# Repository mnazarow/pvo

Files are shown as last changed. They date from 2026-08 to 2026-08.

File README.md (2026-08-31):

# ПВО от комаров 🦟🎯 — карта проекта

Поворотная турель с лазером-целеуказателем по мотивам вирусного видео. Четыре варианта исполнения, у каждого — свой код и своё руководство по сборке.

## Какой файл к какому варианту

| Вариант | Железо | Код | Руководство по сборке |
|---|---|---|---|
| **A «Часовой»** | Uno/Nano + HC-SR04 + 1 серво | `pvo_a_simple/pvo_a_simple.ino` (минимальный) или `pvo.ino` (полный) | `Сборка_вариант_A.docx` |
| **B «Комар-М»** — как в видео | ESP32 + радар LD2450/RD-03D + pan-tilt | `pvo_esp32/pvo_esp32.ino` | `Сборка_вариант_B.docx` |
| **C «Комар-В»** — зрение | Raspberry Pi + камера + турель A | `pvo_vision.py` (на Pi) + `pvo.ino` (в турели) | `Сборка_вариант_C.docx` |
| **D «Комар-Ф»** — слияние | турель B + камера на ней (без ИК-фильтра) + ИК-подсветка | `pvo_fusion.py` (на Pi, рядом кладётся `pvo_vision.py`) + `pvo_esp32.ino` | `Сборка_вариант_D.docx` |

## Общие файлы

- **`ПВО_от_комаров_руководство.docx`** — главный документ: методология, выбор компонентов, программирование, подробное описание **каждого** параметра с примерами, GUI-пульт, эксплуатация, диагностика, замены компонентов.
- **`pvo_gui.py`** — «Пульт ПВО»: приложение для Windows/macOS (Python + pyserial). Живой радарный экран, настройка всех параметров без перепрошивки, ручное управление, консоль. Запуск: `pip install pyserial`, затем `python pvo_gui.py`.
- **`ПВО_список_покупок.xlsx`** — чеклист закупки с ценами и итогами по конфигурациям.
- **`ПВО_с_нуля_для_новичка.docx`** — 59 страниц для человека, который никогда не занимался электроникой: что купить и как не ошибиться, словарь терминов, установка программ со скриншотами, сборка по одному проводу с проверками, каждая настройка простыми словами, типичные ошибки, частые вопросы. Ведёт через все четыре варианта по порядку.
- **`ПВО_шпаргалка_А4.pdf`** — одна страница со всеми командами, параметрами, распиновками и «первой помощью». Распечатать и держать у верстака.
- **`systemd/`** — готовые файлы служб для Raspberry Pi: `pvo.service` (вариант C) и `pvo-fusion.service` (вариант D).

## Быстрый старт (вариант A за вечер)

1. Купите по разделам 1–3 чеклиста (~2200 ₽).
2. Соберите по `Сборка_вариант_A.docx` (схема + 5 шагов).
3. Прошейте `pvo.ino` (Arduino IDE, плата Uno/Nano, порт 9600).
4. Самотест пройдёт сам; поднесите руку — захват, лазер, «поражение» в журнал.
5. Тонкая настройка — из `pvo_gui.py` (вкладка «Параметры», кнопка W сохраняет в плату).

## Демо и тесты — железо не нужно

- В пульте (`pvo_gui.py`) выберите порт **«ДЕМО: Uno»** или **«ДЕМО: ESP32»** — подключитесь к встроенной виртуальной турели: живой радар, параметры, журнал. Идеально, пока посылка едет.
- **Эмулятор AVR**: `bash tests/avr/run_scenarios.sh` — настоящая прошивка, собранная `avr-gcc`, исполняется по тактам (avr8js, движок Wokwi): видно размер во flash/RAM, реальные тайминги и EEPROM, переживающую перезагрузку. Установка: `sudo apt install gcc-avr avr-libc arduino-core-avr` и `(cd tests/avr/js && npm install)`.
- `bash tests/run_tests.sh` — автотесты всего проекта (для GitHub готов workflow: `tests/github-workflow-tests.yml` → скопировать в `.github/workflows/`): обе прошивки компилируются и гоняются по сценариям на заглушках Arduino API (g++), плюс тесты зрения и GUI. Подробности — `tests/README.md`.
- Каждое «поражение» пульт пишет в журнал с временем и координатами; кнопка «Сохранить CSV…» выгружает статистику для Excel. Вариант C с ключом `--save-hits` дополнительно сохраняет кадры захватов в `hits/`.

## Опциональные модули (включаются одним `#define`, глава 12 руководства)

- **Веб-панель по Wi-Fi** (вариант B, включена по умолчанию): турель раздаёт сеть `PVO-Komar`, радар и все параметры — в браузере телефона на `http://192.168.4.1`. Смените пароль в скетче!
- **OLED SSD1306** (`USE_OLED 1`): экран статуса прямо на турели (SDA=21, SCL=22).
- **Озвучка DFPlayer Mini** (`USE_DFPLAYER 1`): «Цель захвачена» вашим голосом; дорожки `/mp3/0001..0005.mp3`, библиотека не нужна.
- **Telegram** (варианты C и D): `PVO_TG_TOKEN`/`PVO_TG_CHAT` — уведомления о захватах с фотокадром.
- **Слияние радара и зрения** (вариант D, глава 13): радар будит зрение и грубо доворачивает турель, камера на турели ведёт цель с точностью 0,1°; ИК-подсветка (GPIO18) открывает охоту на мелочь, которую радар не видит. Запуск: `python3 pvo_fusion.py --detector bright`.
- **Пристрелка лазера** (вариант D): `python3 pvo_fusion.py --calibrate` — скрипт зажигает лазер, находит его точку в кадре и целится потом именно в неё, а не в центр кадра. Без этого шага система стабильно мажет на величину смещения камеры от лазера.
- **Предохранитель сопровождения** (обе прошивки): `TRACKMAX` (по умолчанию 60 с) не даёт турели вести одну «цель» бесконечно — штору на сквозняке или вентилятор. По лимиту лазер и ИК гаснут, турель берёт паузу `TRACKCD`.
- **3D-печать** (`3d/`): параметрический pan-tilt кронштейн, основание варианта A и держатель камеры с кольцом ИК-диодов (вариант D) — .scad + готовые STL + превью.

## Протокол (для своих скриптов)

Текстовые строки + `\n`. Uno 9600: `P<угол>` `R` `?` `G` `S ИМЯ ЗНАЧ` `W` `D` `Z` `M1/M0`. ESP32 115200: `?` `C` `L1/L0` `T` `G` `S …` `W` `D` `Z` `M1/M0` + `V dP dT` (поправка зрения, десятые градуса) и `I1/I0` (ИК) для варианта D. Подробно — руководство, разделы 3.9, 4.5 и глава 13. Версия прошивок печатается при старте и в статусе.

## Безопасность

Лазер — только ≤5 мВт (KY-008). Автонаводящийся лазер мощнее — это травма зрения, а не игрушка. Не ставьте турель на уровне глаз. ИК-подсветка в варианте D — только рассеянные светодиоды, никаких ИК-лазеров: инфракрасный луч невидим, и моргательный рефлекс глаз не защищает.

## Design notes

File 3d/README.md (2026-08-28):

# 3D-печать для «ПВО от комаров»

Параметрические модели OpenSCAD + готовые STL. Перед печатью **замерьте свои серво штангенциркулем** — у клонов SG90/MG90S размеры гуляют на ±0,5 мм; параметры правятся в начале каждого .scad (бесплатный редактор: openscad.org).

## Файлы

| Файл | Что это | STL |
|---|---|---|
| `pvo_pan_tilt.scad` | кронштейн pan-tilt для варианта B: плита с окном PAN-серво, Г-скоба на качалку с окном TILT-серво, площадка радара и лазера с прорезями под стяжки | `stl/pan_tilt_base.stl`, `stl/pan_tilt_bracket.stl`, `stl/pan_tilt_plate.stl` |
| `pvo_base_a.scad` | основание варианта A: окно серво + поле отверстий (шаг 10 мм) под Arduino/макетку на стяжках | `stl/base_a.stl` |
| `pvo_cam_mount.scad` | держатель камеры с кольцом ИК-диодов для варианта D: лицевая панель (окно объектива, 6 гнёзд под диоды 5 мм, винты М2) + люлька с вертикальными пазами регулировки высоты | `stl/cam_face.stl`, `stl/cam_cradle.stl` |

Превью: `preview_pan_tilt.png`, `preview_base_a.png`, `preview_cam_mount.png`.

## Печать

PLA или PETG · слой 0,2 мм · 3 периметра · заполнение 25% · все детали печатаются плашмя, поддержки не нужны. Отверстия под саморезы 2 мм и стяжки уже в моделях; если саморез идёт туго — пройдите отверстие сверлом 2 мм.

## Сборка pan-tilt

1. Плиту (base) — на основание, серво PAN в окно ушами вниз, прикрутить саморезами из комплекта серво.
2. Скобу (bracket) подошвой на круглую крестовину качалки PAN (4 самореза M2 по кругу).
3. Серво TILT — в окно стенки скобы, качалкой наружу.
4. Площадку (plate) — отверстиями на крестовину качалки TILT.
5. Радар и лазер — стяжками в прорези площадки (радар излучателем вперёд, лазер параллельно).
6. Только после прошивки и команды «C» (серво в центры) окончательно затянуть винты качалок «прямо и в горизонт».

## Сборка держателя камеры (вариант D)

В варианте D камера — это прицел: её ось должна быть параллельна лучу лазера и не сдвигаться после пристрелки. Термоклей столько не держит, поэтому камера садится на печатный держатель.

1. Камеру — на лицевую панель (`cam_face`) четырьмя винтами М2, объектив в центральное окно. Плата камеры сзади, объектив смотрит наружу.
2. ИК-диоды 5 мм — в кольцо гнёзд вокруг объектива, ножками назад; спаять параллельно (все аноды вместе, все катоды вместе) и вывести два провода на ключ GPIO18. Если берёте готовую ИК-плату — поставьте `ir_module = true` в начале .scad, и вместо кольца получится окно под неё.
3. Люльку (`cam_cradle`) — стяжками в прорези площадки TILT рядом с лазером, объективом в ту же сторону.
4. Панель — к стойке люльки двумя винтами М2 через **вертикальные пазы**: до затяжки подвиньте панель так, чтобы ось объектива встала на высоту оси лазера. Это и есть механическая часть пристрелки.
5. Остаточное смещение снимается программно: `python3 pvo_fusion.py --calibrate` (глава 13 руководства).

Параметры под свою камеру — в начале `pvo_cam_mount.scad`: `cam_w`, `cam_h`, `cam_hole_s`, `lens_d` (по умолчанию Raspberry Pi Camera v2/NoIR), число и радиус гнёзд диодов — `led_n`, `led_ring_r`.

Регенерация STL из командной строки:
```bash
openscad -o stl/pan_tilt_base.stl -D 'part="base"' pvo_pan_tilt.scad
openscad -o stl/pan_tilt_bracket.stl -D 'part="bracket"' pvo_pan_tilt.scad
openscad -o stl/pan_tilt_plate.stl -D 'part="plate"' pvo_pan_tilt.scad
openscad -o stl/base_a.stl pvo_base_a.scad
openscad -o stl/cam_face.stl -D 'part="face"' pvo_cam_mount.scad
openscad -o stl/cam_cradle.stl -D 'part="cradle"' pvo_cam_mount.scad
```

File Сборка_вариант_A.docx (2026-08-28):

ПВО ОТ КОМАРОВ

Сборка варианта A — «Часовой»

Arduino Uno/Nano + HC-SR04, сканирующая турель · версия 1.0 · август 2026

Лазерная безопасность: только модуль ≤5 мВт (KY-008). Не ставьте турель на уровне глаз, ограничьте сектор так, чтобы луч не выходил в проёмы и окна. Лазеры «burning/engraving» устанавливать запрещено — необратимая травма зрения.

Опциональные модули: веб-панель по Wi-Fi, OLED-экран, озвучка DFPlayer, Telegram-уведомления и 3D-печать кронштейна описаны в главе 12 большого руководства; всё включается одним переключателем в коде и на сборку по этой инструкции не влияет.

# 1. Что получится

Автономная турель: ультразвуковой дальномер и лазер-целеуказатель на качалке серво. Патрулирует сектор 15–165°, при появлении цели ближе 60 см захватывает её, включает лазер, сопровождает и ведёт журнал «поражений». Управляется и настраивается с компьютера (GUI-приложение «Пульт ПВО»). Время сборки — один вечер.

# 2. Комплектующие

Деталь | Кол-во | Примечание
Arduino Uno или Nano | 1 | Nano: драйвер CH340, «Old Bootloader» для клонов
HC-SR04 | 1 | ультразвуковой дальномер
Серво SG90 или MG90S | 1 | MG90S надёжнее
Лазерный модуль KY-008 (≤5 мВт) | 1 | только целеуказатель
Буззер (активный или пьезо) | 1
Макетка, провода Dupont, БП 5 В ≥1 А | — | конденсатор 470–1000 мкФ, если без БП
Основание + крепёж/термоклей | —

Полный чеклист с ценами — файл ПВО_список_покупок.xlsx. Замены компонентов — раздел 8.

# 3. Схема подключения

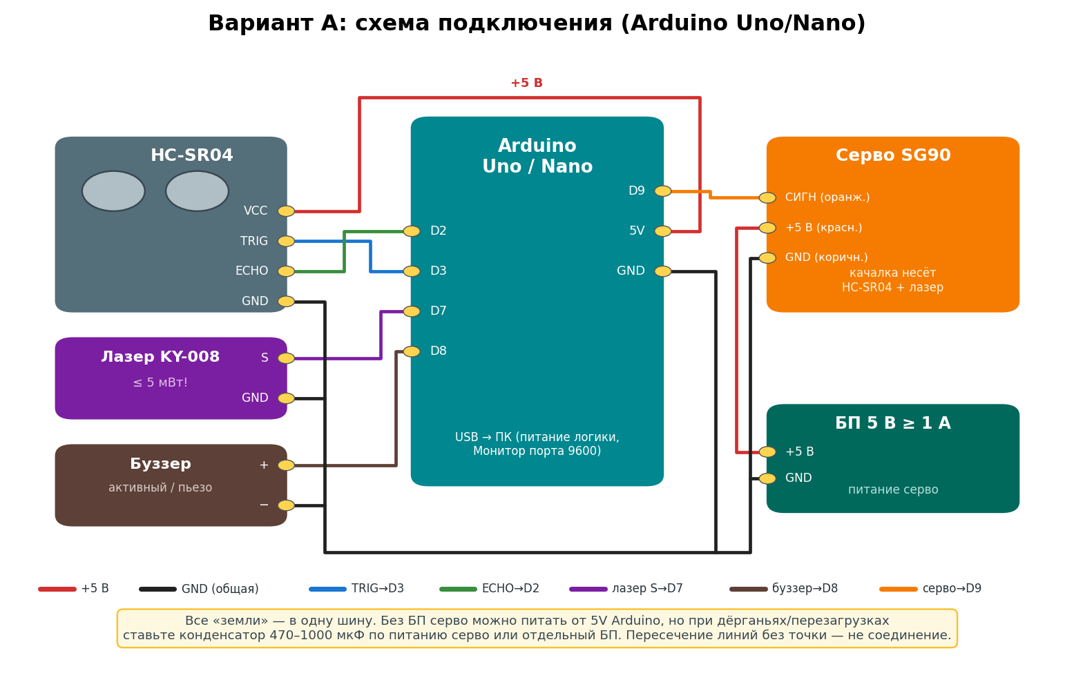
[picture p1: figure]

Монтажная схема варианта A

Модуль | Контакт | Arduino
HC-SR04 | VCC / GND | 5V / GND
HC-SR04 | TRIG / ECHO | D3 / D2
Серво | сигнал / + / − | D9 / БП 5 В / GND
Лазер KY-008 | S / − | D7 / GND
Буззер | + / − | D8 / GND

Питание: серво лучше кормить от отдельного БП 5 В (земли объединить). От USB возможны перезагрузки платы — их выдаёт растущий «счётчик загрузок» в статусе прошивки.

# 4. Механическая сборка

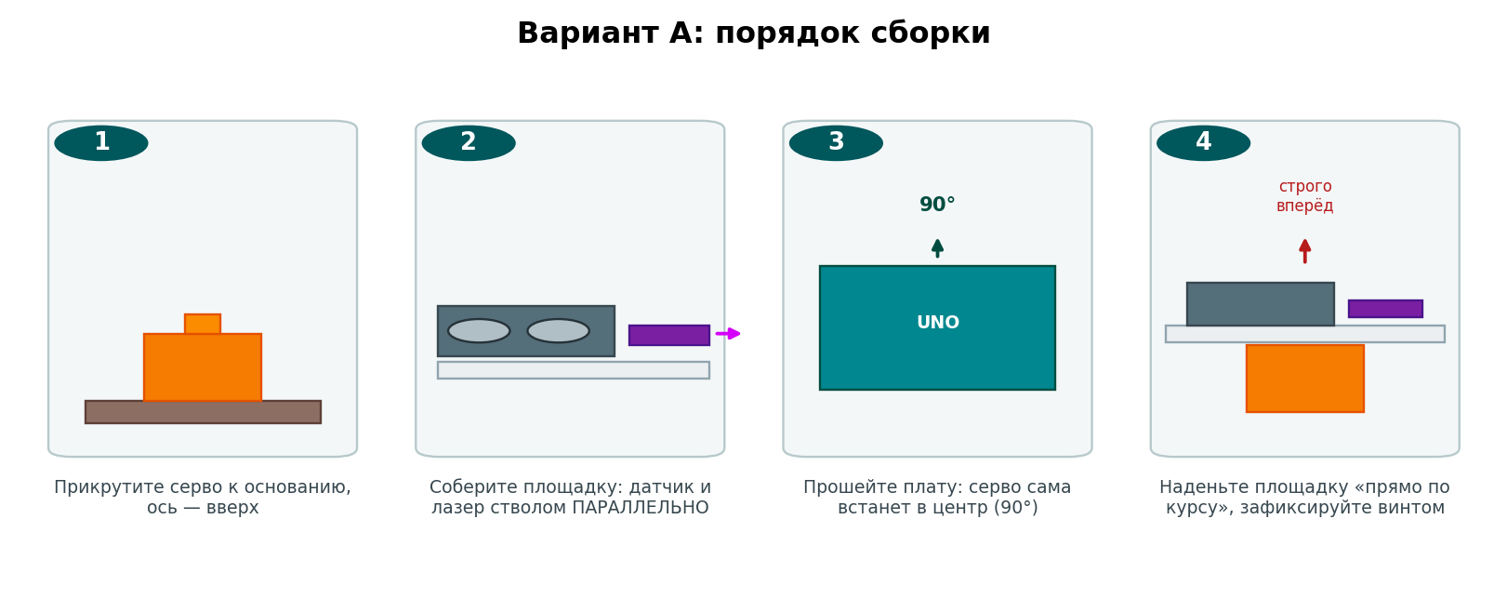
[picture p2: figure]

Порядок сборки

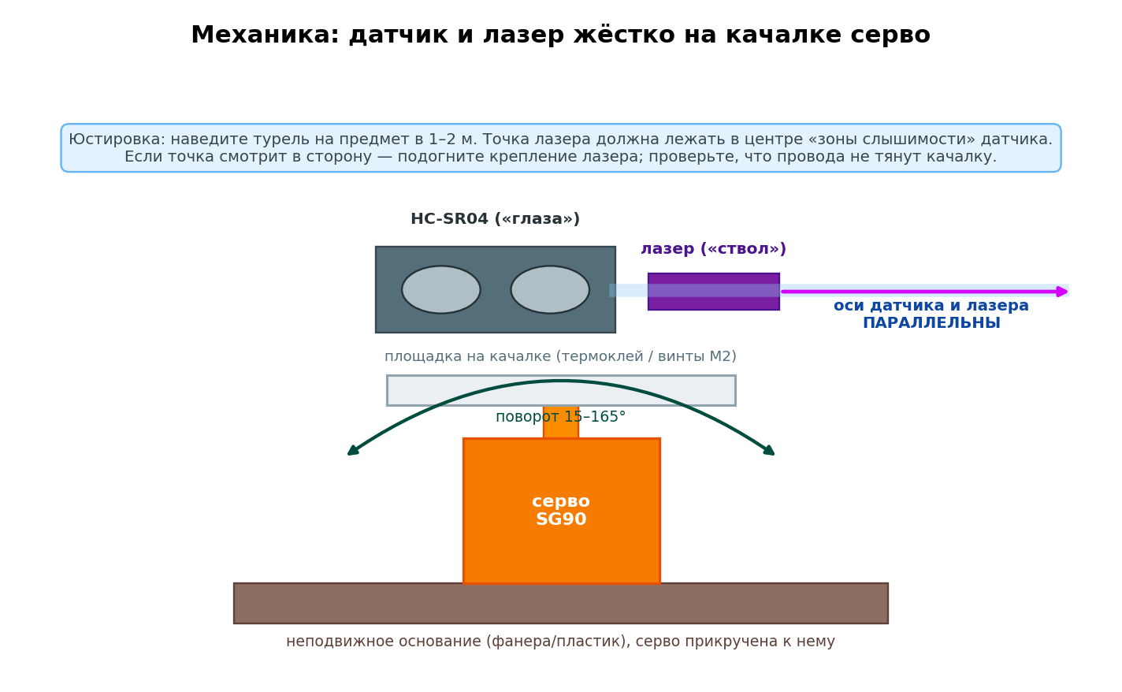
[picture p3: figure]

Взаимное расположение датчика и лазера на качалке

1. Прикрутите серво к основанию, ось вверх.
2. Соберите площадку: HC-SR04 «глазами» вперёд, лазер стволом строго параллельно оси датчика (термоклей/винты М2).
3. Прошейте плату (раздел 5) — при старте серво сама встанет в центр (90°).
4. Наденьте площадку на качалку «прямо по курсу» и зафиксируйте винтом; уложите провода с запасом на поворот.
5. Юстировка: наведите турель на предмет в 1,5–2 м — точка лазера должна лежать в центре «взгляда» датчика; при уводе подогните крепление лазера.

# 5. Прошивка

Какой скетч выбрать. pvo_a_simple.ino — минимальный и понятный: только автономная логика (для первого запуска и изучения кода). pvo.ino — полный: плюс внешнее целеуказание (для связки с Raspberry Pi) и протокол настройки для GUI-приложения. Схема подключения одинаковая; рекомендую сразу pvo.ino.

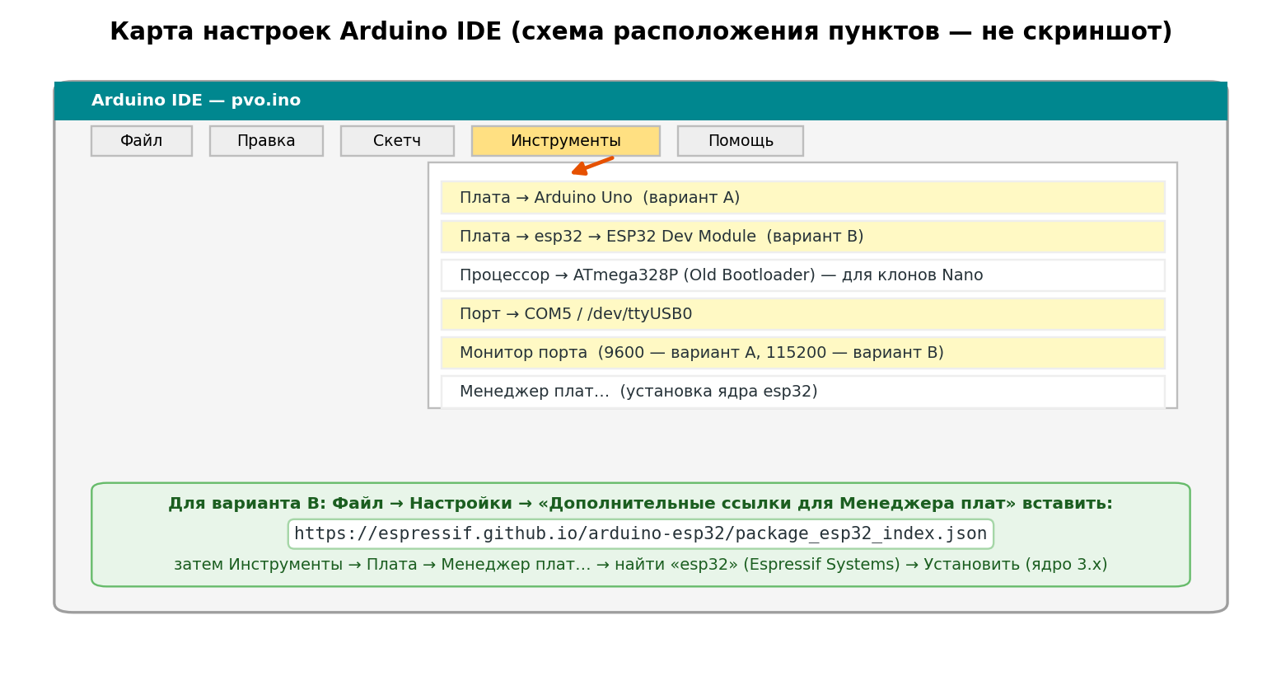
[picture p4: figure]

Карта пунктов Arduino IDE (стилизованная схема)

1. Установите Arduino IDE 2.x (arduino.cc/en/software); для клонов на CH340 — драйвер CH340.
2. Откройте pvo/pvo.ino (или pvo_a_simple/pvo_a_simple.ino).
3. Инструменты → Плата: Arduino Uno (или Nano; для клонов Nano — Процессор: ATmega328P (Old Bootloader)).
4. Инструменты → Порт: выберите появившийся порт. Загрузите скетч.
5. Монитор порта, скорость 9600.

# 6. Первый запуск: что вы увидите

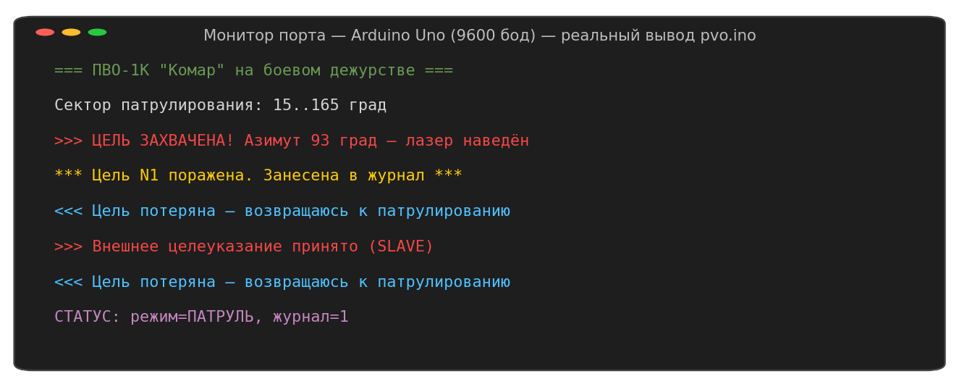
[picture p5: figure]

Реальный вывод прошивки (сценарный прогон)

- Самотест: прогон серво по сектору, два мигания лазера, два сигнала буззера, отчёт «датчик OK (эхо в N/10 замеров)».
- Если датчик молчит — прошивка честно скажет об этом при старте и будет напоминать в работе (тревога снимается сама при появлении эха).
- Строка «Загрузка N…»: если номер растёт сам по себе — плата перезагружается, лечите питание серво.
- Поднесите руку на 30–40 см: захват (писк, лазер), через 3 с — «Цель N1 поражена», журнал хранится в EEPROM и переживает выключение.

Дальше: тонкая настройка всех параметров — из GUI-приложения «Пульт ПВО» (глава 9 большого руководства) или командами S в Мониторе порта; подробное описание каждого параметра — большое руководство, раздел 3.7.

# 7. Если что-то не так

Симптом | Причина и лечение
Серво дёргается, в статусе растут «загрузки» | питание от USB — отдельный БП 5 В, конденсатор, общая земля
«ОШИБКА САМОТЕСТА: датчик не дал ни одного эха» | перепутаны TRIG(D3)/ECHO(D2), нет 5V/GND, битый датчик
Ложные захваты у краёв сектора | датчик ловит стены: уменьшите DETECT (S DETECT 40) или сузьте сектор (S SWMIN/SWMAX)
Цель рядом, захвата нет | цель «мягкая»/узкая — ведите ладонью плашмя; поднимите DETECT
Точка лазера мимо цели | юстировка (раздел 4, шаг 5); жгут тянет качалку
Кракозябры в Мониторе порта | скорость не 9600

# 8. Замены компонентов

Вместо… | Подойдёт | Что поменять
HC-SR04 | HC-SR04P, US-015 | ничего — полные аналоги (P работает и от 3,3 В)
HC-SR04 | US-100 (режим TRIG/ECHO) | ничего; перемычку датчика — в режим Trig/Echo
HC-SR04 | JSN-SR04T (влагозащ.) | S MINVALID 25 (мёртвая зона 20–25 см); в коде PULSE_TIMEOUT_US 30000
Серво SG90 | MG90S | ничего; надёжнее и точнее
Серво SG90 | MG995/MG996R (большая) | ничего в коде; БП 5 В ≥2 А обязателен, крепёж крупнее
Серво SG90 | серво постоянного вращения (FS90R и пр.) | НЕ ПОДХОДИТ: не держит угол
Uno/Nano | Pro Mini, Mega | ничего (Pro Mini: нужен USB-UART переходник для прошивки)
Uno/Nano | ESP32/ESP8266 | не сюда: для ESP32 есть вариант B со своей прошивкой
Буззер активный | пассивный/пьезо | ничего — tone() работает с обоими
KY-008 | голый лазерный диод 650 нм ≤5 мВт | резистор по паспорту диода; мощнее 5 мВт — запрещено
БП 5 В | повербанк | осторожно: многие отключаются при малом токе — турель «умирает» на дежурстве

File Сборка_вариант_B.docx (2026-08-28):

ПВО ОТ КОМАРОВ

Сборка варианта B — «Комар-М»

ESP32 + mmWave-радар LD2450/RD-03D, радарная pan-tilt турель · версия 1.0 · август 2026

Лазерная безопасность: только модуль ≤5 мВт (KY-008). Не ставьте турель на уровне глаз, ограничьте сектор так, чтобы луч не выходил в проёмы и окна. Лазеры «burning/engraving» устанавливать запрещено — необратимая травма зрения.

Опциональные модули: веб-панель по Wi-Fi, OLED-экран, озвучка DFPlayer, Telegram-уведомления и 3D-печать кронштейна описаны в главе 12 большого руководства; всё включается одним переключателем в коде и на сборку по этой инструкции не влияет.

# 1. Что получится

Турель «как в видео»: 24-ГГц радар сам отдаёт координаты до трёх движущихся целей, двухосевая турель мгновенно наводится и сопровождает ближайшую. Дальность до 4–6 м, автоматический наклон по дальности, сервисная консоль, настройка всех параметров из GUI-приложения, журнал в энергонезависимой памяти.

# 2. Комплектующие

Деталь | Кол-во | Примечание
ESP32 DevKit (WROOM-32, 30 pin) | 1 | ядро Arduino-ESP32 3.x
Радар HLK-LD2450 или Ai-Thinker RD-03D | 1 | переключатель RADAR_TYPE в скетче
Серво MG90S | 2 | pan и tilt
Pan-tilt кронштейн под SG90/MG90S | 1 | готовый комплект
Транзистор 2N2222 + резистор 1 кОм | 1+1 | ключ лазера
Лазер KY-008 (≤5 мВт), буззер | 1+1
БП 5 В ≥2 А, провода, основание | —

# 3. Схема подключения

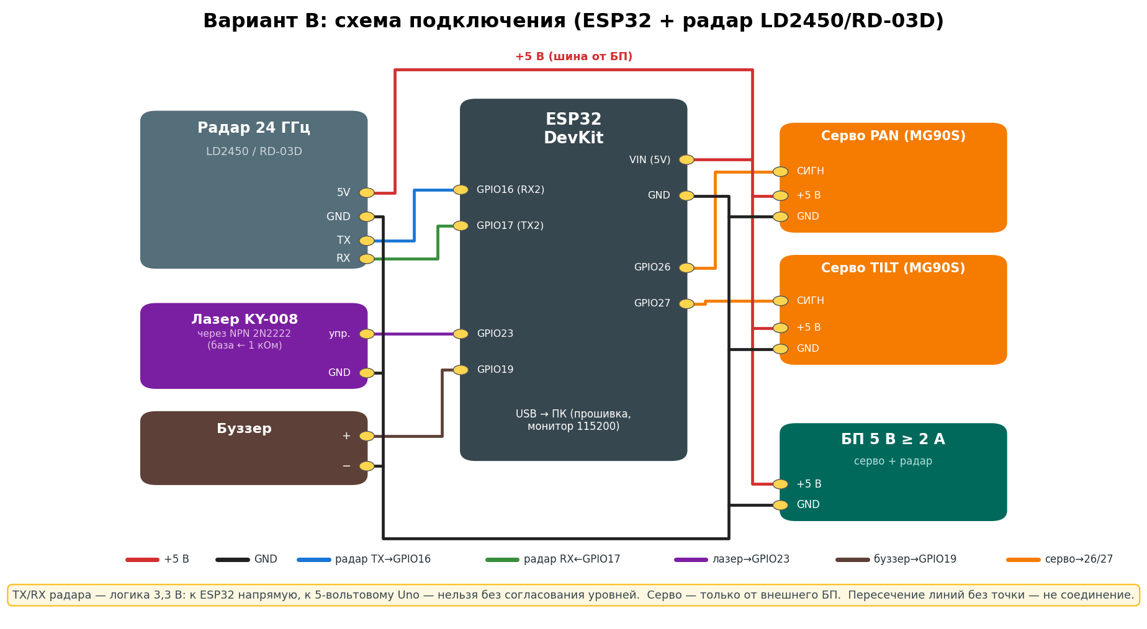
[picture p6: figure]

Монтажная схема варианта B

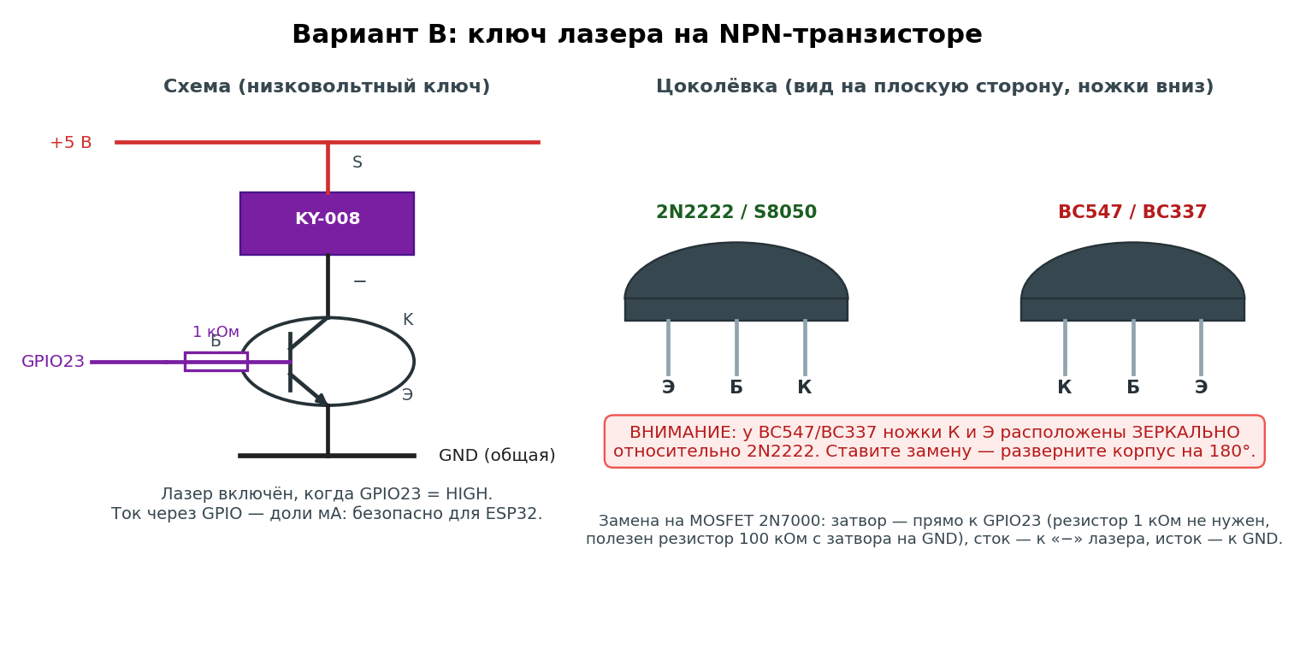
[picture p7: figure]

Ключ лазера и цоколёвки транзисторов

Уровни: TX/RX радара — логика 3,3 В, к ESP32 напрямую. Радар часто приходит без распаянной гребёнки — понадобится паяльник. Серво и радар питаются от внешнего БП 5 В; земли БП, ESP32 и модулей — в одну шину.

# 4. Механическая сборка

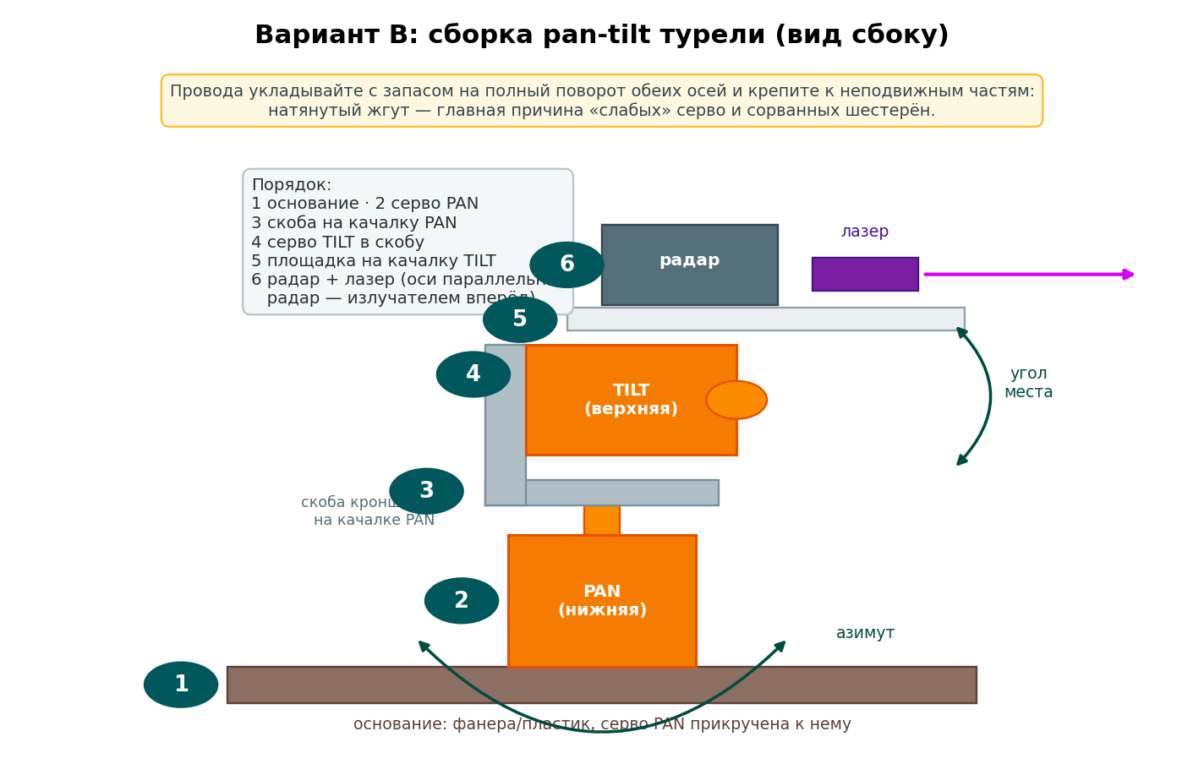
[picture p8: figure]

Порядок сборки pan-tilt

1. Соберите кронштейн: нижняя серво (PAN) осью вверх на основание, скоба на её качалку, верхняя серво (TILT) в скобу, площадка на качалку TILT.
2. Радар закрепите на площадке излучателем вперёд (антенны — плоской стороной к цели), лазер — рядом, стволом параллельно оси радара.
3. Прошейте плату (раздел 5): при старте серво встанут в центры (90/90) — только после этого окончательно фиксируйте качалки «прямо и в горизонт».
4. Уложите жгут с запасом на полный ход обеих осей.
5. Юстировка: команда C в Мониторе порта (или кнопка «Серво в центр» в GUI) держит центры 8 секунд — удобно проверять соосность; точку лазера сведите с осью радара на 2–3 м.

# 5. Прошивка

1. Файл → Настройки → «Дополнительные ссылки для Менеджера плат»: https://espressif.github.io/arduino-esp32/package_esp32_index.json
2. Инструменты → Плата → Менеджер плат… → «esp32» (Espressif Systems) → установить 3.x.
3. Менеджер библиотек → установить «ESP32Servo».
4. Откройте pvo_esp32/pvo_esp32.ino; вверху выставьте RADAR_TYPE: 0 = LD2450, 1 = RD-03D.
5. Плата: ESP32 Dev Module; порт (драйвер CP210x или CH340 — по чипу платы); при «Connecting…» держите кнопку BOOT.
6. Монитор порта 115200.

# 6. Первый запуск: что вы увидите

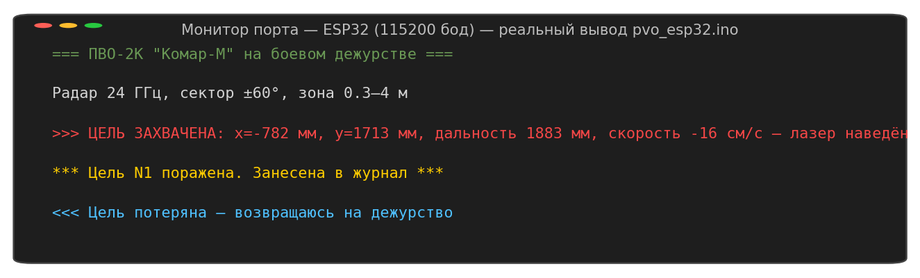
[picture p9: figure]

Реальный вывод прошивки (сценарный прогон)

- Самотест: серво в центры, два мигания лазера, сигнал; баннер с номером загрузки и журналом (хранится в NVS — переживает выключение).
- Пройдите перед радаром: захват с координатами цели (x, y, дальность, скорость), лазер сопровождает; 3 секунды удержания — «поражение».
- Отключите радар на лету — прошивка объявит тревогу, погасит лазер, вернёт турель в центр и будет переинициализировать радар, пока он не оживёт (тревога снимется сама).
- Сервисная консоль: ? статус · C центр · L1/L0 тест лазера · T реинициализация радара · G/S/W/D параметры · M1 телеметрия для GUI.

Если турель крутит «не туда»: пройдите слева направо — она должна повернуть за вами; иначе S PANINV 1 (и/или S TILTINV 1), затем W. Подробно о каждом параметре — большое руководство, раздел 4.5.

# 7. Если что-то не так

Симптом | Причина и лечение
«ТРЕВОГА: радар молчит» | нет 5 В на радаре; радар TX не на GPIO16; TX/RX перепутаны
«ПОДСКАЗКА: много битых кадров» | плохие провода/длинные, наводки — короче провода, скрутка
RD-03D видит только одну цель | команда мультирежима шлётся при старте и при тревоге сама; проверьте RADAR_TYPE 1
Скетч не заливается («Connecting…») | держите BOOT; кабель с данными; правильный драйвер
Серво жужжат и греются на дежурстве | S PATROL 0 (отключить патруль) или пределы дальше от упоров
Точка лазера выше/ниже цели по дальности | S TURH/TGTH — реальные высоты турели и цели (мм), затем W

# 8. Замены компонентов

Вместо… | Подойдёт | Что поменять
HLK-LD2450 | Ai-Thinker RD-03D | RADAR_TYPE 1 — и всё (протокол данных совместим)
RD-03D | HLK-LD2450 | RADAR_TYPE 0
LD2450/RD-03D | LD2410, LD2410C | НЕ ПОДХОДИТ: датчик присутствия, координат не отдаёт
ESP32 WROOM DevKit | ESP32-S3/C3 платы | работает, но пины другие (RX2/TX2, каналы ШИМ) — правьте PIN_*; для новичка проще WROOM
ESP32 | ESP8266 | НЕ ПОДХОДИТ: нет свободного аппаратного UART на 256000
MG90S | SG90 | работает, люфт больше; MG996R — БП ≥2 А и крупный кронштейн
2N2222 | S8050, PN2222 | ничего (цоколёвка ЭБК совпадает)
2N2222 | BC337, BC547 | цоколёвка ЗЕРКАЛЬНАЯ (КБЭ) — корпус на 180°
2N2222 | MOSFET 2N7000/AO3400 | затвор к GPIO23 без 1 кОм; 100 кОм затвор-GND
KY-008 | лазерный модуль 3,3–5 В ≤5 мВт | мощнее 5 мВт — запрещено

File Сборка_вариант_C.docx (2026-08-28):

ПВО ОТ КОМАРОВ

Сборка варианта C — «Комар-В»

Raspberry Pi + камера (OpenCV) + турель варианта A · версия 1.0 · август 2026

Лазерная безопасность: только модуль ≤5 мВт (KY-008). Не ставьте турель на уровне глаз, ограничьте сектор так, чтобы луч не выходил в проёмы и окна. Лазеры «burning/engraving» устанавливать запрещено — необратимая травма зрения.

Опциональные модули: веб-панель по Wi-Fi, OLED-экран, озвучка DFPlayer, Telegram-уведомления и 3D-печать кронштейна описаны в главе 12 большого руководства; всё включается одним переключателем в коде и на сборку по этой инструкции не влияет.

# 1. Что получится

Гибрид: Raspberry Pi со зрением находит движущуюся цель в кадре (вплоть до мелкой — муха/комар на контрастном фоне вблизи) и диктует турели углы по USB. Турель остаётся автономной: пропала связь — сама вернулась к патрулю с ультразвуком. Требуется собранный вариант A с прошивкой pvo.ino (полной).

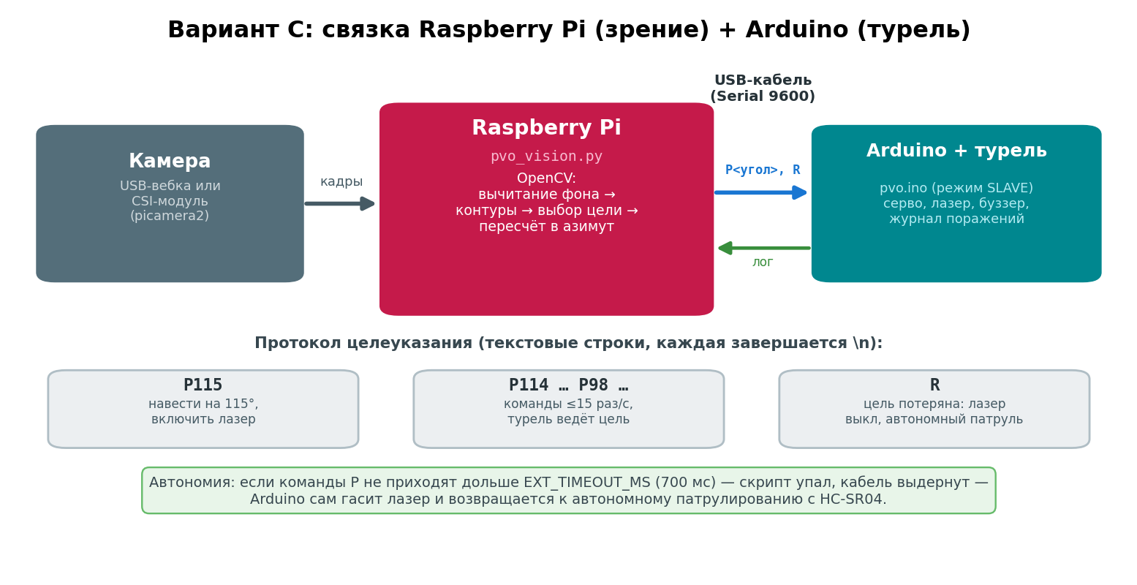
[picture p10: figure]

Архитектура и протокол целеуказания

# 2. Комплектующие

Деталь | Кол-во | Примечание
Собранный вариант A (прошивка pvo.ino) | 1 | см. «Сборка варианта A»
Raspberry Pi 4 (2–4 ГБ) или Pi 5 | 1 | Zero 2 W работает (меньше FPS)
Камера: USB 720p+ или CSI-модуль | 1 | CSI лучше при слабом свете
microSD 16+ ГБ, БП USB-C 5 В/3 А | — | качественный БП обязателен
USB-кабель к Arduino | 1 | тот же, что для прошивки

# 3. Компоновка

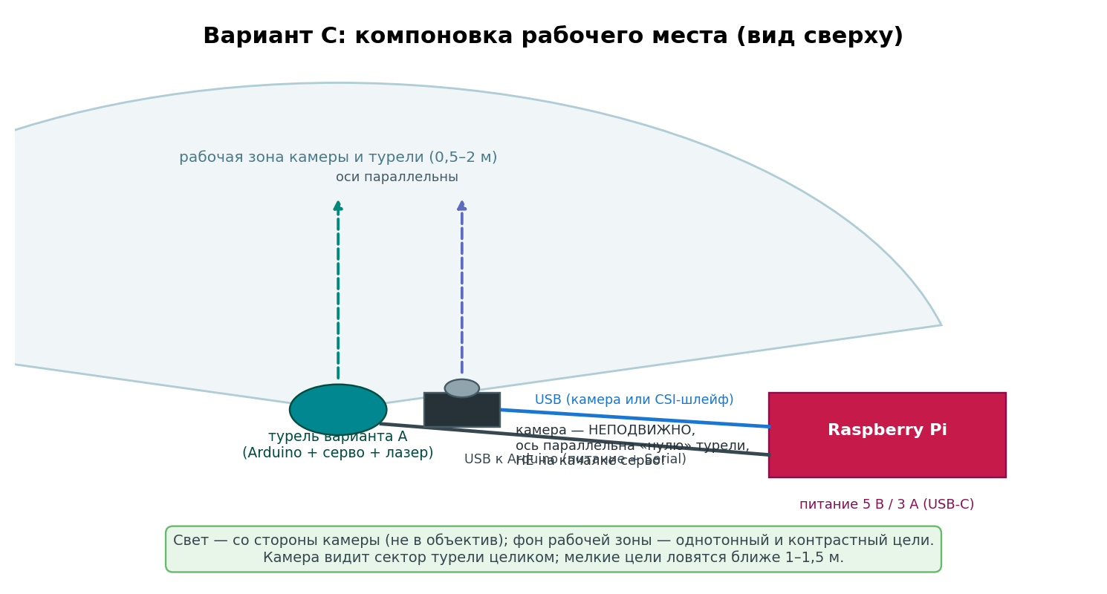
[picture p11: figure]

Размещение камеры, турели и Raspberry Pi

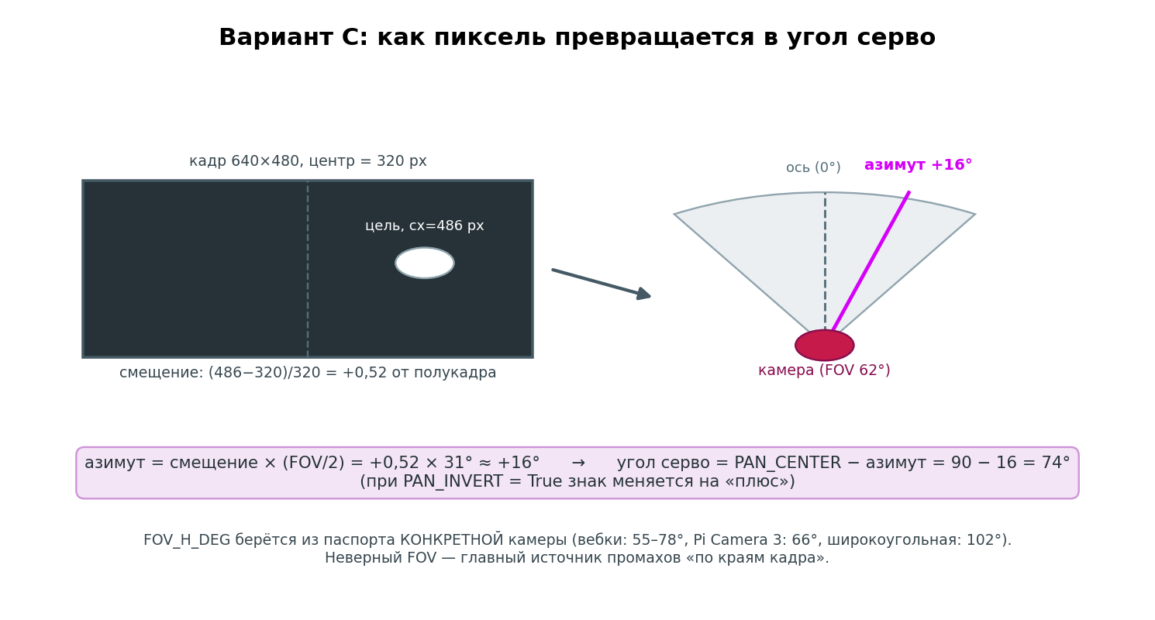
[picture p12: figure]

Как позиция цели в кадре превращается в угол серво

- Камера — неподвижно рядом с турелью (не на качалке!), оптическая ось параллельна «нулю» турели (90°).
- Свет — со стороны камеры; фон рабочей зоны — однотонный, контрастный целям.
- Угол обзора вашей камеры впишите в FOV_H_DEG (или ключ --fov) — это главный параметр точности по краям кадра.

# 4. Установка ПО на Raspberry Pi

1. Raspberry Pi Imager → Raspberry Pi OS (64-bit); в настройках образа задайте пользователя, Wi-Fi, включите SSH.
2. sudo apt update && sudo apt full-upgrade
3. sudo apt install python3-opencv python3-serial python3-numpy
4. Для CSI-модуля: sudo apt install python3-picamera2 (USB-вебке не нужно).
5. Скопируйте pvo_vision.py на Pi; Arduino подключите по USB (порт скрипт найдёт сам).
6. Права на порт: sudo usermod -aG dialout $USER и перелогин.

# 5. Запуск и проверка

1. Сухой прогон: python3 pvo_vision.py --dry-run --display — рамка цели и угол в окне, команды в консоли.
2. Боевой: python3 pvo_vision.py (CSI: --picamera; свой FOV: --fov 66). Порт Arduino ищется автоматически.
3. Остановка Ctrl+C — скрипт сам отправит R, турель вернётся к автономному патрулю.

Автозапуск службой systemd (файл /etc/systemd/system/pvo.service):

[Unit]

Description=PVO-3K vision

After=multi-user.target

[Service]

ExecStart=/usr/bin/python3 /home/pi/pvo_vision.py

Restart=on-failure

User=pi

[Install]

WantedBy=multi-user.target

Активация: sudo systemctl enable --now pvo.service; логи: journalctl -u pvo -f

# 6. Встроенная устойчивость (что чинится само)

- Порт Arduino не найден / USB выдернут: скрипт пишет «ОБРЫВ СВЯЗИ… переподключаюсь» и восстанавливает связь сам; турель на это время — в автономном патруле.
- Камера зависла/пропала: после серии пустых кадров скрипт переоткрывает её автоматически.
- Скрипт упал/выключили Pi: у турели сработает таймаут EXT_TIMEOUT_MS (700 мс) — лазер погаснет, патруль продолжится.
- Странные значения в CONFIG ловятся проверкой на старте («ПРЕДУПРЕЖДЕНИЕ КОНФИГА: …»).

# 7. Если что-то не так

Симптом | Причина и лечение
Permission denied на порту | sudo usermod -aG dialout $USER, перелогин
Детектор видит всё подряд | мерцающий свет, низкий BG_THRESHOLD — поднимите; MIN_AREA_PX больше
Мелкую цель не видит | мало света/контраста; MIN_AREA_PX 8–15, MORPH_KERNEL 1–3, камеру ближе
[stat] FPS низкий | уменьшите FRAME_W/H; закройте лишнее на Pi
Турель наводится мимо по краям кадра | неверный FOV_H_DEG — калибровка (большое руководство, 5.5)
Турель дёргается между двумя целями | детектор берёт крупнейший контур — уберите второй источник движения из кадра

# 8. Замены компонентов

Вместо… | Подойдёт | Что поменять
Raspberry Pi 4 | Pi 5 | ничего; быстрее
Raspberry Pi 4 | Zero 2 W | FRAME 320×240, ниже FPS; для мелких целей слабовата
Raspberry Pi | любой ПК/ноутбук с Linux/Windows | скрипт кроссплатформенный: тот же python3 + opencv + pyserial
USB-вебка | CSI Camera Module (v2/3) | флаг --picamera; пакет python3-picamera2; FOV свой
USB-вебка | IP-камера | не поддержано из коробки (можно добавить cv2.VideoCapture(rtsp://…))
Uno/Nano в турели | — | обязателен pvo.ino (полная прошивка) — режим SLAVE

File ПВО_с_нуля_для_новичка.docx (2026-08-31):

ПВО ОТ КОМАРОВ

С НУЛЯ

Пошаговое руководство для тех, кто никогда этим не занимался

Что купить · как соединить · как прошить · как настроить · что делать, когда не работает

Все четыре варианта: от простой турели за вечер

до системы со зрением, радаром и ночной охотой

Версия 1.0 · август 2026 · дополняет «ПВО от комаров — руководство»

Оглавление

# Часть 0. Прежде чем что-то покупать

## 0.1. Что мы построим — и чего эта штука не делает

Мы соберём небольшую поворотную установку: она сама осматривает комнату, замечает движущуюся цель, поворачивается к ней, светит на неё лазерной указкой и записывает «поражение» в журнал. Выглядит это ровно как в том вирусном ролике, с которого начался проект.

И сразу — самое важное, чтобы не было разочарования. Комаров эта установка не убивает. В ролике человек использовал промышленный радар и лазер такой мощности, который в домашних условиях просто опасен. У нас лазер — обычная указка до 5 милливатт, то есть светящаяся точка, а не оружие. «Поражение» в нашем проекте — это событие в журнале: турель удержала точку на цели заданное время. Всё остальное — настоящее: обнаружение, наведение, сопровождение, потеря цели, статистика.

Это отличный первый электронный проект. Вы за один вечер получите штуку, которая живёт своей жизнью на столе и реагирует на вас, а попутно научитесь всему базовому: подключать датчики, управлять приводами, заливать программу в плату, читать её сообщения и настраивать поведение под свою комнату.

Как связаны два документа

Эта книга — не замена большому «ПВО от комаров — руководство», а вход в него. Там те же вещи изложены плотнее и для человека с опытом; здесь всё разжёвано, с объяснением каждого слова. Когда освоитесь — переходите туда, там больше деталей и таблиц.

## 0.2. Безопасность: прочитайте до покупки

В проекте есть ровно две вещи, которые действительно способны навредить, и обе связаны со светом. Разберём их сразу, потому что решение принимается на этапе покупки — потом будет поздно.

### Лазер

Лазерная указка кажется безобидной, но глаз — это линза, которая собирает весь луч в одну точку на сетчатке. Указка до 5 мВт (класс 3R) считается относительно безопасной именно потому, что человек успевает моргнуть и отвернуться раньше, чем возникнет ожог. Лазеры мощнее — те, что продают как «burning», «engraving», «выжигающие» — повреждают сетчатку быстрее, чем срабатывает рефлекс, причём иногда даже отражённым от стены лучом. Повреждение сетчатки не восстанавливается.

- Покупайте только модуль KY-008 или аналог мощностью до 5 мВт. В описании товара должно быть «5 мВт» или «5mW». Если написано «100 мВт», «1 Вт», «прожигает бумагу» — это не для этого проекта.
- Наша турель наводится сама. Это принципиально отличает её от указки в руке: вы не контролируете, куда пойдёт луч. Значит, ставить её нужно так, чтобы луч в принципе не мог попасть в глаза: ниже или выше уровня глаз сидящего человека, сектором в стену, а не в дверной проём или окно.
- Не проверяйте лазер глазом. Чтобы убедиться, что он горит, посмотрите на пятно на стене, а не в излучатель.
- Дети и животные. Кошки обожают гоняться за красной точкой и смотрят на неё в упор. Если в доме есть кот, ограничьте сектор и не оставляйте турель работать без присмотра.

Запомните формулу: лазер, которым можно было бы сбить комара, — это лазер, которым можно ослепить человека. Поэтому в нашем проекте лазер только показывает, куда смотрит турель.

### Инфракрасная подсветка (понадобится только в самом конце, в варианте D)

Инфракрасный свет глаз не видит — и в этом опасность: моргательный рефлекс не срабатывает, потому что мозг не понимает, что в глаз что-то светит. Поэтому правило простое: в проекте используются только рассеянные ИК-СВЕТОДИОДЫ (такие же стоят в любой камере видеонаблюдения), и ни при каких условиях — ИК-лазеры. Не смотрите в излучатель в упор и направляйте подсветку в рабочую зону, а не на людей.

## 0.3. Сколько это стоит и сколько займёт времени

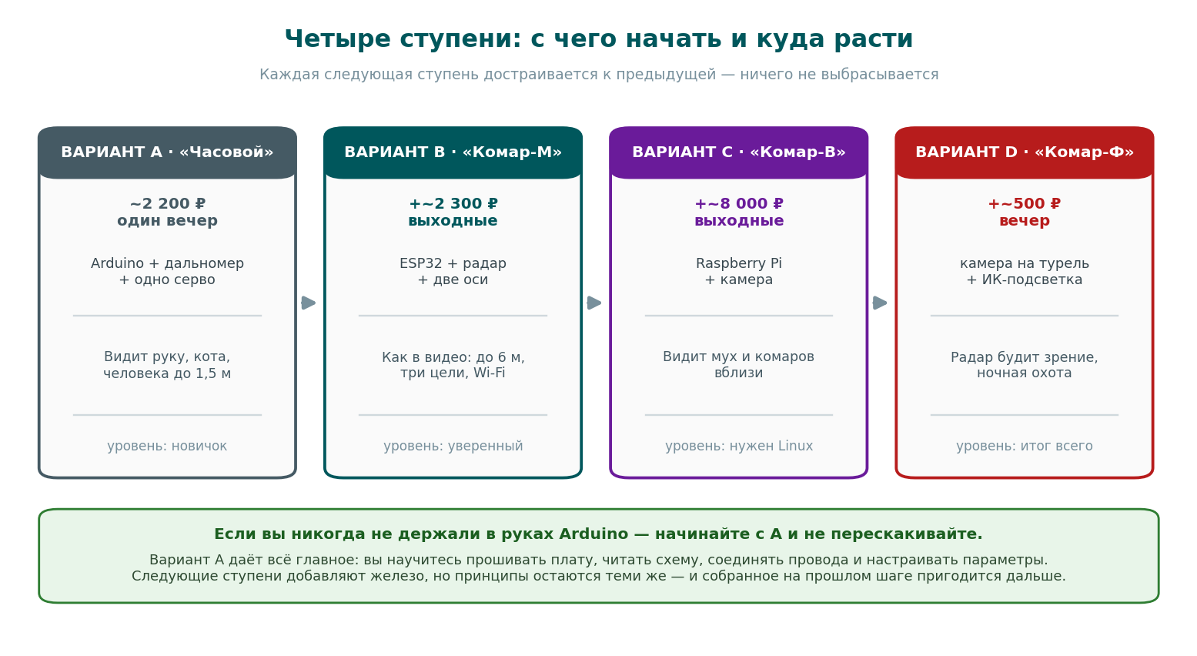
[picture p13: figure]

Рис. 1. Четыре ступени проекта: начинать нужно с левой

Ступени устроены так, что каждая следующая достраивается к предыдущей. Собрав вариант A, вы не «выбросите» его при переходе к B — детали и навыки останутся с вами. Поэтому не пытайтесь сразу прыгнуть в конец: даже если вам интересен только финальный вариант D, дорога к нему всё равно идёт через A и B.

Ступень | Что добавляется | Доплата | Сколько времени | Что нужно уметь
A «Часовой» | Arduino, ультразвуковой дальномер, одно серво, лазер, буззер | ~2 200 ₽ | один вечер | ничего заранее
B «Комар-М» | ESP32, радар, вторая ось поворота, транзистор | ~2 300 ₽ | выходные | то, чему научились в A
C «Комар-В» | Raspberry Pi, камера, карта памяти, блок питания | ~8 000 ₽ | выходные | не бояться командной строки
D «Комар-Ф» | камера переезжает на турель, ИК-подсветка, транзистор | ~500 ₽ | вечер | собранные B и C

Цены ориентировочные, на август 2026 года, по обычным маркетплейсам. Точный список с ценами и итогами — в файле «ПВО_список_покупок.xlsx», который идёт с проектом: там можно отмечать купленное галочками, а суммы посчитаются сами.

## 0.4. Словарь: слова, которые будут встречаться

Здесь собрано всё, что может показаться непонятным. Не пытайтесь выучить это наизусть — просто возвращайтесь сюда, когда встретите незнакомое слово.

Слово | Что это на самом деле
Плата (Arduino Uno, Nano) | маленький компьютер размером со спичечный коробок, у которого нет экрана и клавиатуры, зато есть ножки-контакты, к которым подключают датчики и моторчики. Выполняет одну-единственную программу, которую вы в него запишете
Скетч | так в мире Arduino называется программа. Файл с расширением .ino
Прошить (залить) | записать программу в плату через USB-кабель. После этого плата выполняет её сама, даже если отсоединить компьютер
Пин | контакт (ножка) платы. У каждого есть имя: D2, D7, 5V, GND. Именно по именам мы говорим, куда воткнуть провод
GND («земля», минус) | общий ноль схемы, точка отсчёта для всех напряжений. Все минусы всех устройств соединяются вместе
5V | пять вольт — питание для датчика, лазера и буззера
Серво (сервопривод) | моторчик, который поворачивается не «крутится», а «встаёт в заданный угол»: скажешь 90 — повернётся на 90 градусов и удержит
Дальномер HC-SR04 | ультразвуковой «локатор»: пищит неслышимым для человека звуком и по времени возврата эха вычисляет расстояние
Макетная плата (макетка) | белая пластиковая доска с дырочками, позволяющая собрать схему без пайки: провода просто втыкаются
Провода «дюпон» | готовые проводки с наконечниками. «Папа» — штырёк, «мама» — гнездо. Бывают папа-папа, папа-мама, мама-мама
Монитор порта | окошко в программе Arduino, куда плата пишет свои сообщения. Через него турель рассказывает, что видит
Бод (baud) | скорость общения платы с компьютером. Должна совпадать с обеих сторон, иначе вместо текста будут «кракозябры». У нас 9600 или 115200
Порт (COM3, /dev/ttyUSB0) | имя, под которым компьютер видит подключённую плату. В Windows — COM с номером, в Linux и на Raspberry Pi — /dev/ttyUSB0 или похожее
EEPROM | маленькая память внутри платы, которая не стирается при выключении. Мы храним в ней настройки и счётчик «поражений»
Библиотека | готовый кусок чужого кода, который умеет что-то конкретное (например, крутить серво). Подключается одной строкой
IDE | программа, в которой пишут и заливают скетчи. У нас — Arduino IDE
Параметр | настройка поведения турели: дальность захвата, скорость, длительность. Их можно менять на лету, не переписывая программу

## 0.5. Что понадобится из инструментов

Хорошая новость: для варианта A паяльник не нужен вообще — всё собирается на макетной плате проводами. Понадобится буквально следующее.

- Компьютер с USB-разъёмом (Windows, macOS или Linux — всё равно) и правом устанавливать программы.
- Маленькая крестовая отвёртка — прикрутить качалку к серво.
- Термоклеевой пистолет или двусторонний скотч — закрепить датчик и лазер на качалке. Клей-пистолет удобнее и стоит копейки.
- Кусок фанеры, доски или толстого картона как основание. Подойдёт даже крышка от коробки.
- Желательно, но не обязательно: мультиметр (проверить, есть ли питание) и паяльник (понадобится в варианте B, если модули придут с гребёнками «в пакетике»).

Совет из практики

Отдельное рабочее место лучше стола на кухне: мелкие детали любят падать и теряться, а провода — цепляться. Хватит подноса или коробки, куда можно всё убрать одним движением.

## 0.6. Как пользоваться этой книгой

Книга устроена как дорога: части идут в том порядке, в каком стоит собирать. Не пытайтесь читать всё подряд перед началом — читайте по мере дел. Пока едет посылка, полезно прочитать часть 0 и раздел 1.3 (подготовка компьютера): всё остальное будет понятнее с деталями в руках.

Значок | Что означает
Синяя рамка | пояснение: почему всё устроено именно так. Можно пропустить, но с ней понятнее
Жёлтая рамка | предупреждение: здесь легко ошибиться, читайте внимательно
Красная рамка | безопасность: место, где можно навредить себе или технике
Зелёная рамка | хорошая новость или подтверждение, что всё идёт правильно
Фиолетовая рамка | совет из практики: не обязательно, но сильно упрощает жизнь
Нумерованный список | делайте по порядку, не перескакивая
Моноширинный шрифт | то, что нужно набрать буквально: команды и имена файлов

Если что-то не получается — это нормально и почти всегда поправимо. В книге есть раздел 1.11 с таблицей «симптом → причина → лечение» и приложение Д с расшифровкой всех сообщений турели. Больше половины проблем новичка — это кабель без данных, забытая общая земля или провод в соседней колонке макетки.

# Часть 1. Ваша первая турель (вариант A)

Это главная часть книги. Если вы дойдёте до её конца, у вас будет работающая турель и понимание, как она устроена. Всё остальное — надстройки.

## 1.0. План первого вечера

Если детали уже на столе, вся сборка занимает примерно полтора часа с перерывом на чай. Вот как распределяется время — сверяйтесь, чтобы понимать, где вы находитесь.

Время | Чем заняты | Раздел
15 минут | установить Arduino IDE, подключить плату, залить в неё пример Blink | 1.3
10 минут | разобрать посылку, опознать детали, проверить лазер и кабель | 1.2
25 минут | собрать схему на макетке: питание, серво, датчик, лазер, буззер | 1.5
15 минут | приклеить датчик и лазер на качалку, закрепить серво на основании | 1.5
10 минут | залить прошивку турели и посмотреть самотест | 1.6, 1.7
20 минут | настроить под свою комнату: сектор, дальность, подтверждения | 1.9
5 минут | сохранить настройки и позвать кого-нибудь смотреть | 1.10

Не делайте всё за один заход, если устали. Электроника не прощает невнимательности, а усталость её порождает. Лучше отложить сборку до завтра, чем перепутать питание и потом искать сгоревший модуль.

## 1.1. Что купить: список с пояснениями

Список ниже — то, что нужно именно для варианта A. Названия даны так, как они обычно пишутся в объявлениях; можно копировать в поиск.

Что искать | Сколько | Цена | На что обратить внимание
Arduino Nano (CH340) или Arduino Uno R3 | 1 | ~400–600 ₽ | берите с УЖЕ распаянными ножками (в описании — «с гребёнками», «soldered»). Клон на чипе CH340 дешевле и полностью подходит
Ультразвуковой датчик HC-SR04 | 1 | ~100 ₽ | самый обычный, четырёхногий. Есть версия HC-SR04P — тоже подойдёт
Сервопривод SG90 (или MG90S) | 1 | ~160–230 ₽ | MG90S дороже, но с металлическими шестерёнками — живёт дольше и меньше люфтит
Лазерный модуль KY-008, красный | 1 | ~100 ₽ | СТРОГО до 5 мВт. Идёт с тремя ножками: S (сигнал), плюс, минус
Буззер активный, 5 В | 1 | ~50 ₽ | «таблетка» с двумя ножками. Активный сам пищит; пассивный тоже сработает
Макетная плата 830 точек | 1 | ~250 ₽ | можно взять на 400 точек — тоже хватит
Набор проводов «дюпон» 3×40 | 1 | ~250 ₽ | обязательно набор из трёх видов (п-п, п-м, м-м), длина 20 см
Блок питания 5 В / 2–3 А | 1 | ~450 ₽ | с обычным круглым штекером 5,5×2,1 мм. Зарядка от телефона тоже подойдёт, если сможете подключить провода
Переходник «штекер → клеммник» | 1 | ~60 ₽ | чтобы подключить блок питания к макетке без пайки
Конденсатор 1000 мкФ / 16 В | 2 | ~20 ₽ | сглаживает рывки серво. Копеечная деталь, которая экономит нервы
USB-кабель для платы | 1 | ~150 ₽ | ВАЖНО: с проводами данных. Дешёвые «зарядные» кабели не годятся — плата просто не определится

Самая частая ошибка при покупке — кабель. Кабели, которые идут в комплекте с повербанками и дешёвыми зарядками, часто содержат только провода питания. Плата от такого кабеля загорится светодиодом, но компьютер её не увидит, и вы полдня будете искать проблему в драйверах. Если плата не определяется — первым делом попробуйте другой кабель.

Если хочется купить всё одним заказом, посмотрите «стартовые наборы Arduino»: в них обычно уже есть плата, макетка, провода, серво и датчик. Часто это дешевле, чем покупать по отдельности.

## 1.2. Посылка приехала: разбираем и опознаём

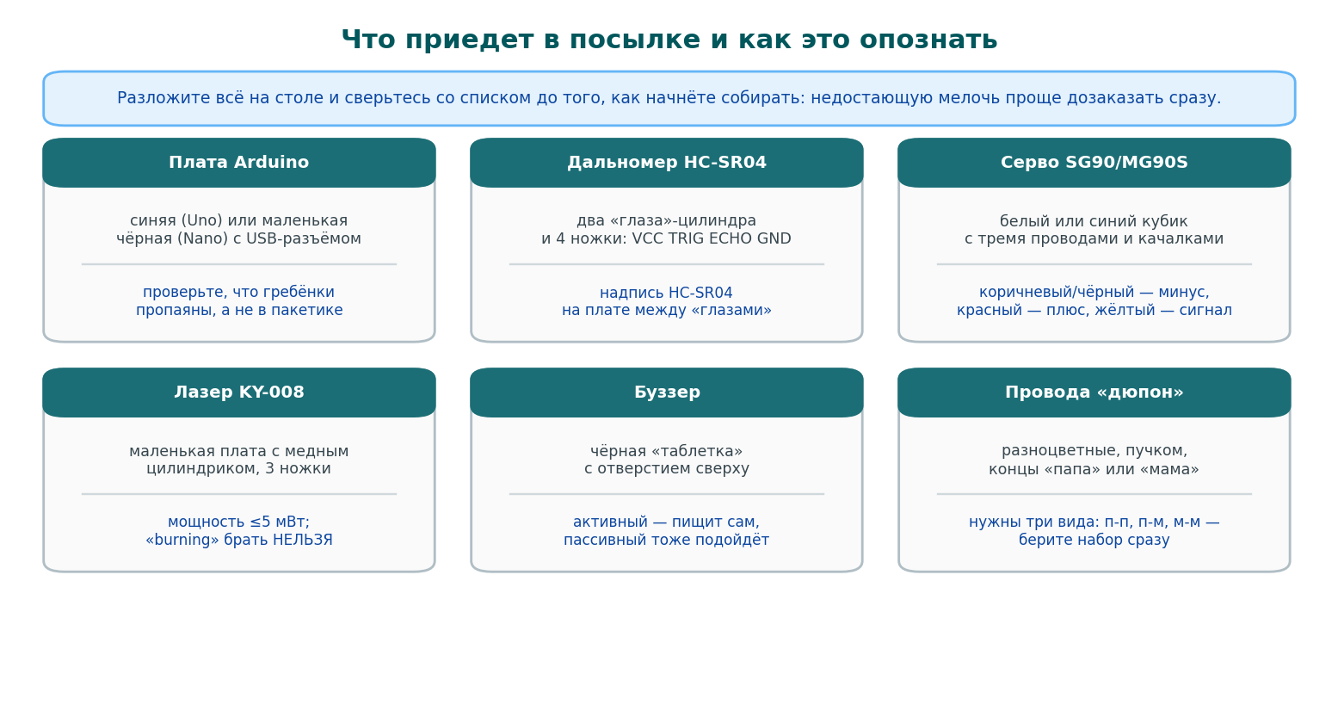
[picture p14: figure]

Рис. 2. Как выглядят детали и на что смотреть

Разложите всё на столе и сверьтесь со списком. Проверьте три вещи, которые лучше выяснить сразу, пока не поздно вернуть товар:

1. У платы распаяны ножки? Если гребёнки лежат отдельно в пакетике — их придётся припаять. Для варианта A это критично: без ножек плату некуда воткнуть.
2. Лазер правильной мощности? На модуле или в описании должно быть до 5 мВт. Если пришло что-то мощное — отложите и купите правильный, это вопрос зрения.
3. Кабель с данными? Проверить просто: воткните плату в компьютер. Если в системе появится новое устройство — кабель хороший.

## 1.3. Готовим компьютер

### Шаг 1. Установить Arduino IDE

1. Откройте сайт arduino.cc/en/software и скачайте «Arduino IDE» для своей системы. Программа бесплатная.
2. Установите обычным способом. В Windows соглашайтесь на предложение установить драйверы — они пригодятся.
3. Запустите. Откроется окно с пустым скетчем.

### Шаг 2. Драйвер для платы (только Windows, только для клонов)

Дешёвые платы используют микросхему CH340 для связи по USB. Windows её иногда не знает. Признак: плата воткнута, а в списке портов пусто, либо в диспетчере устройств висит «неизвестное устройство». Лечится установкой драйвера CH340 — он ищется по названию, ставится за минуту, после чего компьютер надо перезагрузить. В macOS и Linux ничего ставить не нужно.

### Шаг 3. Проверить, что плата жива

Прежде чем собирать схему, убедитесь, что связка «компьютер — кабель — плата» работает. Для этого зальём в плату готовый пример, который просто мигает встроенным светодиодом.

1. Подключите плату кабелем. На ней загорится маленький светодиод питания.
2. В Arduino IDE: меню Файл → Примеры → 01.Basics → Blink.
3. Меню Инструменты → Плата — выберите «Arduino Uno» или «Arduino Nano» (что у вас).
4. Меню Инструменты → Порт — выберите появившийся порт (в Windows это COM с номером, в Linux — /dev/ttyUSB0). Если портов несколько, отключите плату, посмотрите, какой пропал, — он и есть ваш.
5. Нажмите кнопку со стрелкой вправо («Загрузка»). Внизу побегут строчки, потом появится «Загрузка завершена».
6. Светодиод на плате начнёт мигать раз в секунду. Поздравляю: самое сложное для новичка — заставить компьютер увидеть плату — позади.

Рис. 3. Так выглядит Arduino IDE с открытым скетчем нашего проекта

Если Nano не прошивается и в конце пишет ошибку про «avrdude: stk500_recvMessage()», попробуйте в меню «Инструменты → Процессор» выбрать «ATmega328P (Old Bootloader)» — у большинства дешёвых Nano стоит именно старый загрузчик.

## 1.4. Немного теории — ровно столько, сколько нужно

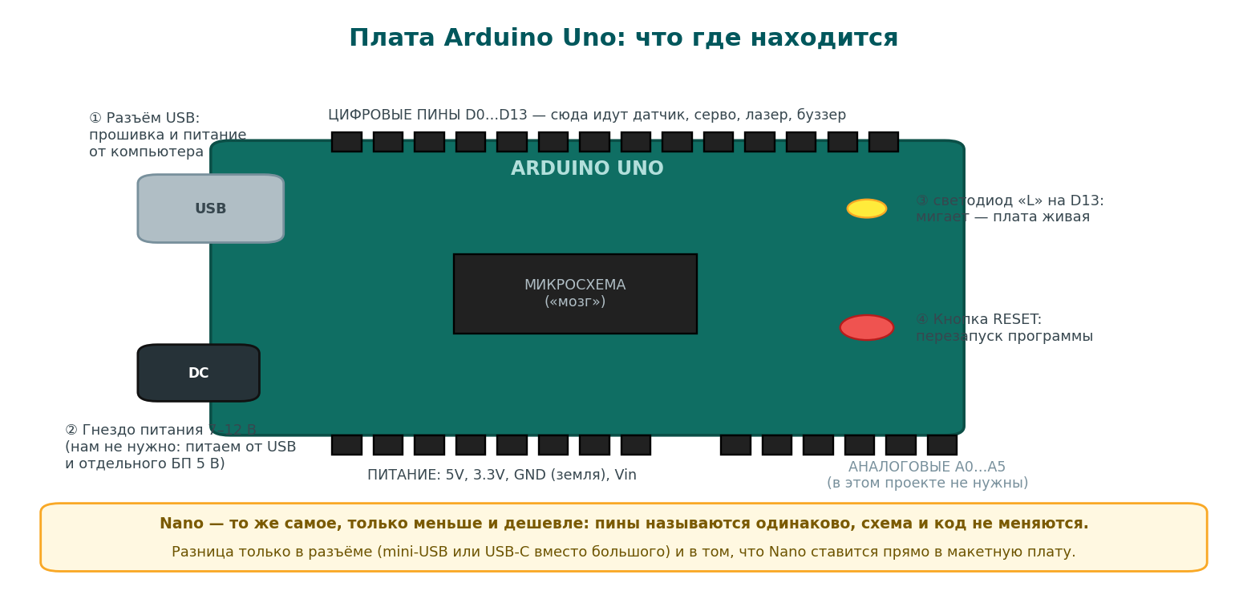
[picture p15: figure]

Рис. 4. Плата Arduino: что где

Плата — это маленький компьютер, который умеет две вещи: подавать напряжение на свои ножки (пины) и измерять напряжение на них. Всё остальное — следствие. Когда мы «включаем лазер», плата подаёт 5 вольт на пин D7. Когда «слушаем датчик», плата засекает, сколько времени на пине D2 держится высокое напряжение.

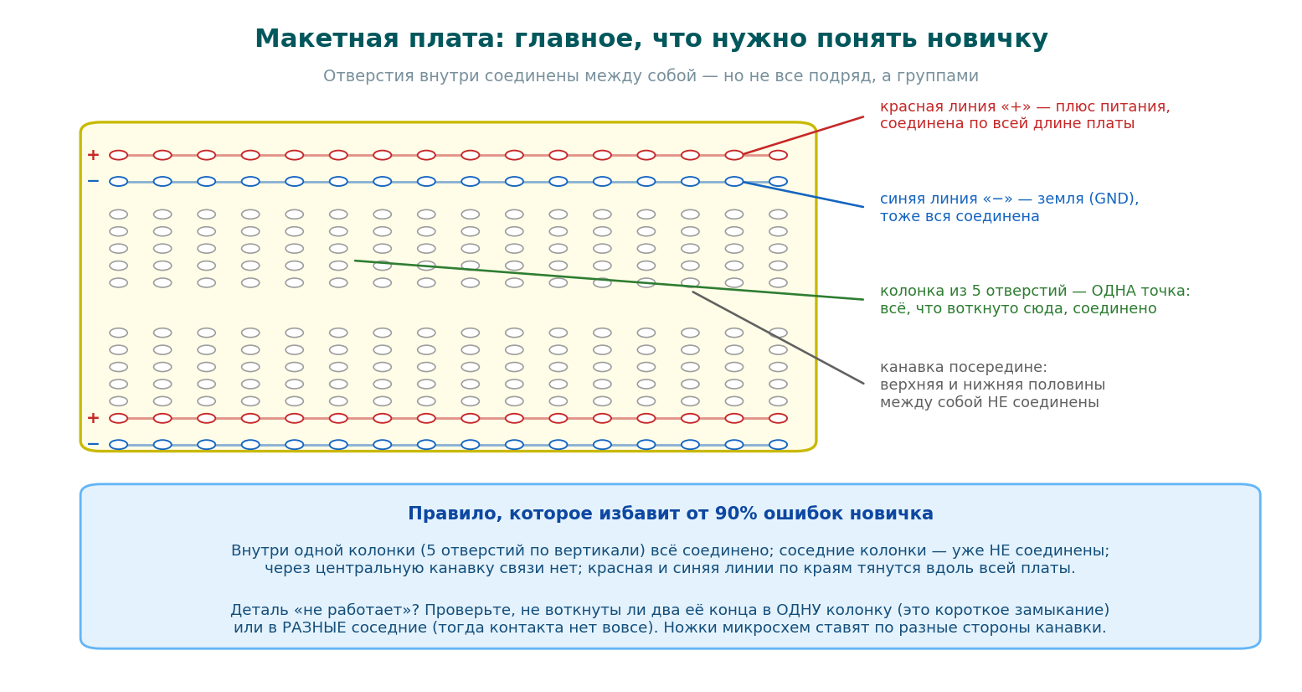
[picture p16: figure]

Рис. 5. Устройство макетной платы — самое важное на первой сборке

Макетка нужна, чтобы соединять провода без пайки. Внутри неё металлические пружинки, которые соединяют отверстия группами. Понимание этих групп — 90% успеха: почти все «не работает» у новичков объясняются тем, что провод воткнут в соседнюю колонку.

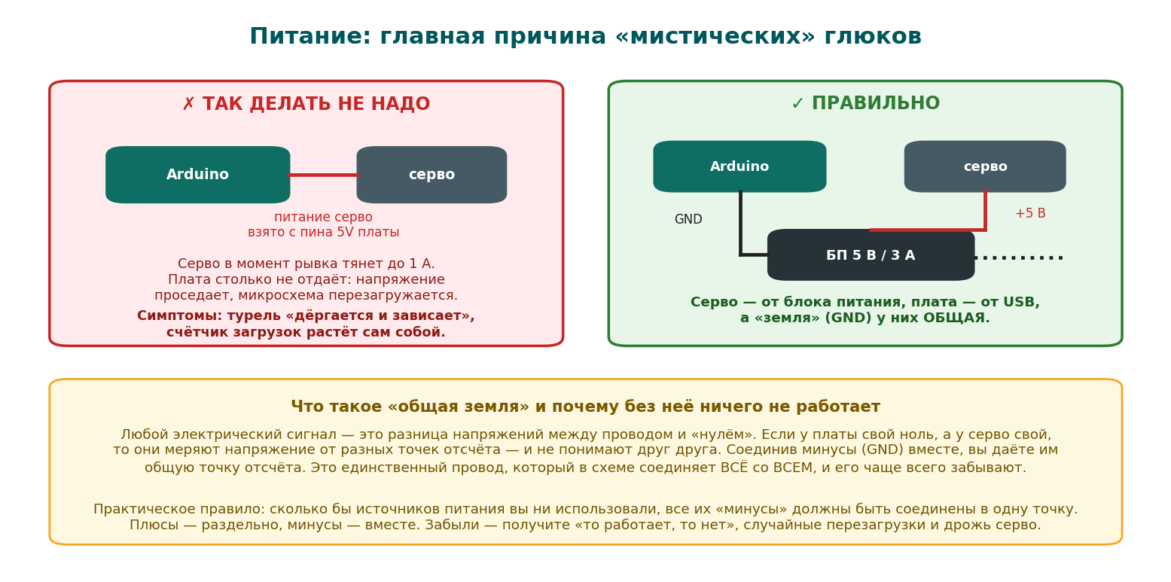
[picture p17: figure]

Рис. 6. Питание: почему серво нельзя питать от платы

И третья вещь, которую нужно понять до сборки, — питание. Сервопривод в момент поворота потребляет ток, который плата отдать не может. Если запитать серво от пина 5V, напряжение просядет, микроконтроллер перезагрузится, и турель будет вести себя «мистически»: дёргаться, замирать, начинать всё сначала. Поэтому серво питается от отдельного блока питания, а минусы (GND) блока питания и платы соединяются вместе.

## 1.4a. Как читать схему подключения

Схемы в этой книге нарисованы одинаково, и если понять принцип один раз, дальше вы будете читать их с листа. На схеме нет «красиво нарисованных проводов» — есть линии, каждая из которых означает один провод, который вы физически воткнёте.

Что видите | Что это значит на столе
Красная линия | провод питания: идёт к «плюсу» — на пин 5V платы или на красную шину макетки
Чёрная или серая линия | земля (минус, GND). Все чёрные линии в итоге сходятся в одну точку
Цветная линия с подписью «D3», «GPIO26» | сигнальный провод: один конец в названный пин платы, другой — в названную ножку модуля
Прямоугольник с названием | модуль: датчик, серво, лазер. Подписи внутри — это надписи на его ножках
Подпись у линии | имя пина. Именно по ним и соединяют: «ECHO → D2» значит «ножку ECHO датчика соединить с пином D2 платы»

Порядок соединения значения не имеет: можно начать с любого провода. Имеет значение только то, что каждая линия схемы должна превратиться ровно в один провод, и наоборот — лишних проводов быть не должно.

Проверяйте себя пальцем. Когда схема кажется собранной, поставьте палец на первую линию схемы и найдите соответствующий провод на столе. Потом вторую, третью. Это скучно ровно две минуты и экономит час поисков.

## 1.4b. Что происходит внутри программы

Знать это не обязательно, но с пониманием настраивать гораздо приятнее. Программа турели устроена как автомат с четырьмя состояниями — она всё время находится ровно в одном из них.

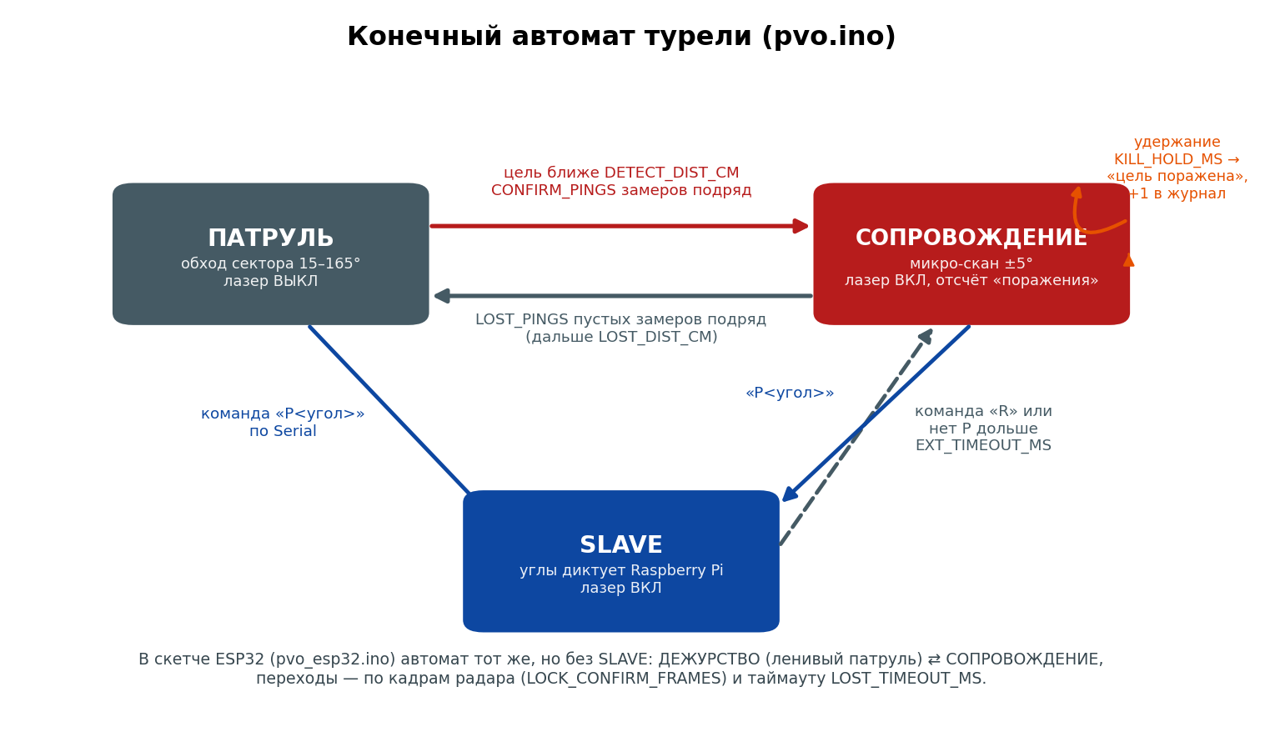
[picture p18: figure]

Рис. 6а. Четыре состояния турели и переходы между ними

Состояние | Что турель делает | Что вы видите
ПАТРУЛЬ | медленно осматривает сектор и меряет расстояние | серво плавно ходит туда-сюда, лазер выключен
ЗАХВАТ | проверяет: цель появлялась CONFIRM раз подряд? | доли секунды, глазом не заметно
СОПРОВОЖДЕНИЕ | ведёт цель, слегка покачиваясь вокруг неё | лазер горит, турель следует за вами
ПОТЕРЯ | цель не видна LOSTP замеров подряд — отпускает | лазер гаснет, звучит короткий сигнал, турель возвращается к патрулю

Важная деталь: порог захвата (DETECT) и порог потери (LOST) специально разные. Если бы они совпадали, турель на границе дальности начала бы «моргать»: захват — потеря — захват. Такой приём называется гистерезисом и встречается везде, от термостатов до автопилотов.

## 1.4c. Что можно сломать (и почему бояться почти нечего)

Новички часто боятся что-нибудь испортить и из-за этого не пробуют. Разберёмся честно, что действительно опасно, а что нет.

Действие | Последствия
Загрузить в плату неправильную программу | ничего страшного: залейте правильную поверх. Плату невозможно «испортить» скетчем
Поменять любой параметр на любое значение | ничего: команда D вернёт заводские. Прошивка сама отвергает значения вне разумных границ
Перепутать сигнальные провода между собой | чаще всего просто не работает; повредить трудно
Воткнуть питание задом наперёд | вот это опасно: модуль может выйти из строя. Всегда проверяйте «плюс к плюсу»
Питать серво от платы | не сломает сразу, но плата будет перезагружаться, а в худшем случае выгорит стабилизатор
Соединить «плюс» и «минус» напрямую | короткое замыкание: в лучшем случае сработает защита блока питания, в худшем он погибнет
Смотреть в лазер | единственное по-настоящему необратимое действие в этом списке. Не делайте так

Вывод: экспериментировать с программой и настройками можно смело — это обратимо. Осторожность нужна ровно в двух местах: полярность питания и лазер.

## 1.5. Сборка: по одному проводу

Рис. 7. Пять шагов сборки — после каждого проверяем

Собирать всё сразу и потом искать ошибку — плохая стратегия. Мы будем добавлять по одному узлу и проверять его. Питание при этом отключено: воткнули провода — включили — посмотрели — выключили — идём дальше.


Рис. 8. Полная схема соединений варианта A

### Шаг 1. Питание макетки

Соедините пин 5V платы с красной шиной «+» макетки, а пин GND — с синей шиной «−». Блок питания через переходник-клеммник подключите к тем же шинам: плюс к «+», минус к «−». Да, к одним и тем же шинам: плата будет питаться от USB, серво — от блока питания, а общая земля свяжет их в одну систему.

### Шаг 2. Сервопривод

Провод серво | Куда
коричневый или чёрный | синяя шина «−»
красный | красная шина «+» (питание от блока, не от платы)
жёлтый или оранжевый | пин D9 на плате

Рядом с серво поставьте конденсатор 1000 мкФ: длинная ножка в «+», короткая в «−». Он работает как маленький аккумулятор и гасит просадки при рывках. Полярность важна: если поставить наоборот, конденсатор может вздуться.

### Шаг 3. Дальномер

Ножка датчика | Куда | Что это
VCC | красная шина «+» | питание
TRIG | пин D3 | сюда плата даёт команду «пискни»
ECHO | пин D2 | отсюда датчик отвечает «эхо вернулось»
GND | синяя шина «−» | земля

TRIG и ECHO легко перепутать — это ошибка номер один. Симптом: датчик показывает всегда одно и то же (обычно 0 или максимум). Если сомневаетесь, поменяйте эти два провода местами и посмотрите, изменится ли поведение.

### Шаг 4. Лазер и буззер

У лазерного модуля три ножки: S (сигнал) — на D7, средняя (плюс) — на «+», минус — на «−». Буззер: плюсовая ножка (обычно длинная или отмечена «+») — на D8, вторая — на «−».

### Шаг 5. Механика


Рис. 9. Как закрепить датчик и лазер на качалке серво

1. Прикрутите к серво пластиковую качалку (крестовину) — она идёт в комплекте.
2. Приклейте датчик на качалку так, чтобы «глаза» смотрели строго вперёд.
3. Рядом приклейте лазер, направив его туда же, куда смотрит датчик. Точная настройка будет позже — сейчас достаточно «на глаз».
4. Само серво приклейте или прикрутите к основанию. Проверьте, что провода не мешают повороту и не тянут качалку.

Не приклеивайте ничего «намертво», пока не проверили работу. Термоклей снимается, но нервы тратятся. Первую сборку удобно делать на двустороннем скотче.

## 1.6. Заливаем программу турели

1. Скачайте файлы проекта. Нам нужен файл pvo_a_simple/pvo_a_simple.ino — это простая версия, с которой стоит начать.
2. Откройте его двойным щелчком: Arduino IDE запустится сама. Если спросит «переместить в папку со скетчами» — соглашайтесь.
3. Проверьте Инструменты → Плата и Инструменты → Порт — как в разделе 1.3.
4. Нажмите «Загрузка». Через 10–20 секунд появится «Загрузка завершена».
5. Откройте Инструменты → Монитор порта и в правом нижнем углу окна выберите скорость 9600 бод — иначе вместо текста будут иероглифы.

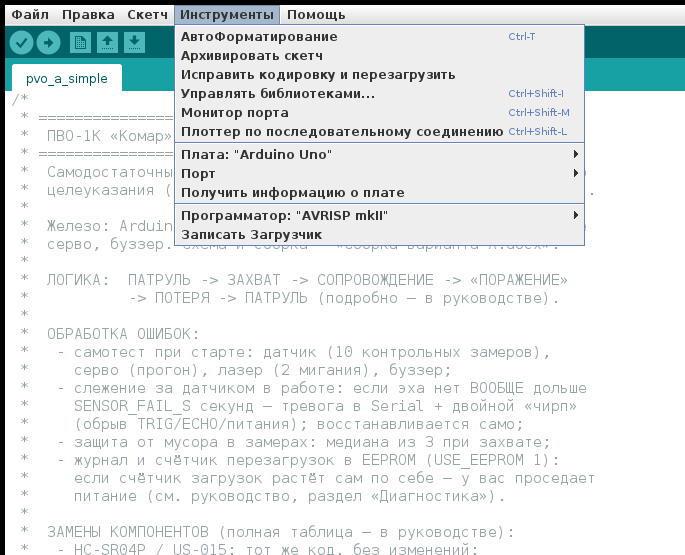
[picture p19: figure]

Рис. 10. Меню «Инструменты»: здесь выбирается плата, порт и открывается монитор

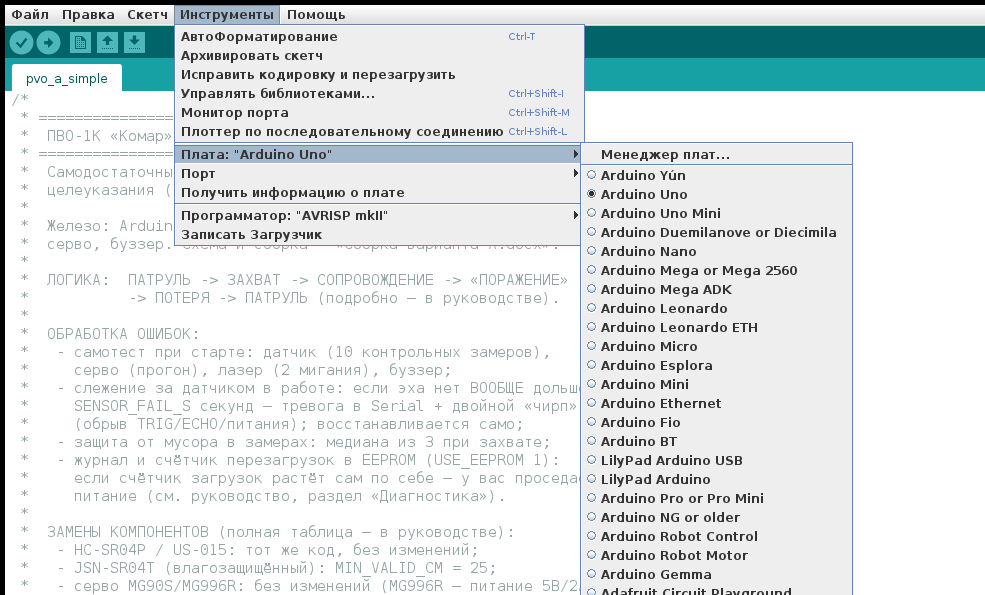
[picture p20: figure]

Рис. 11. Выбор платы: Uno или Nano — смотрите, что у вас

Рис. 12. Выбор порта. На снимке Linux; в Windows здесь будут COM3, COM4 и подобные

## 1.7. Первое включение: что должно произойти

Подайте питание. Дальше события развиваются по расписанию — сверяйтесь с ним, это лучший способ понять, всё ли собрано правильно.

Когда | Что происходит | Если не происходит
сразу | серво поворачивается вправо-влево и встаёт в центр | нет питания серво, не тот пин, серво неисправно
через секунду | лазер мигает два раза | перепутаны ножки лазера, не тот пин
ещё через секунду | буззер коротко пищит два раза | буззер вставлен наоборот (у активного важна полярность)
в мониторе порта | «Самотест: датчик OK (эхо в 10/10 замеров…)» | датчик не отвечает: проверьте TRIG/ECHO и питание
дальше | серво медленно ходит по сектору — это патруль | проверьте, не мешает ли что-то механически
когда поднесёте руку | «ЦЕЛЬ ЗАХВАЧЕНА! Азимут …» и лазер загорается | цель ближе 3 см или дальше 60 см — попробуйте с полуметра
через 3 секунды | «Цель N1 поражена» и весёлая трель | цель ушла из зоны раньше — держите руку неподвижно
когда уберёте руку | «Цель потеряна» и лазер гаснет | —


Рис. 13. Так выглядит вывод турели в мониторе порта

Поздравляю. Если вы дочитали до этого места и всё это увидели — у вас работает первый электронный проект, собранный своими руками. Дальше будет только интереснее: научимся настраивать характер турели.

## 1.7a. Юстировка: чтобы луч светил туда, куда смотрит датчик

Датчик и лазер приклеены рядом, но смотрят чуть-чуть в разные стороны — это неизбежно. Пока цель далеко, разница не видна, но на расстоянии метра луч может уйти в сторону на ладонь. Исправляется за пять минут.

1. Поставьте перед турелью коробку или книгу на расстоянии полутора метров.
2. Дайте турели захватить её (или в пульте на вкладке «Управление» наведите вручную на 90 градусов).
3. Посмотрите, куда легло пятно лазера. Оно должно быть примерно там, где «смотрят глаза» датчика.
4. Если пятно ушло в сторону — аккуратно подогните или переклейте лазер, а не меняйте настройки. Это механика, программой её не исправить.
5. Повторите проверку на другом расстоянии — на полуметре и на двух метрах. Пятно должно оставаться на цели.

Не гонитесь за идеалом: ультразвуковой датчик «видит» довольно широким конусом (около 15 градусов), поэтому попадание «примерно в цель» — это норма для варианта A. Точное совмещение понадобится позже, в варианте D, где прицелом становится камера.

## 1.8. Пульт: управлять турелью мышкой, а не командами

Монитор порта — это хорошо, но неудобно. В проекте есть «Пульт ПВО» — программа с окнами, кнопками и живым радарным экраном. Она работает на Windows, macOS и Linux, и с ней настройка превращается в игру: подвинул ползунок — посмотрел, что изменилось.

### Установка

1. Установите Python с сайта python.org/downloads. Важно для Windows: на первом экране установщика поставьте галочку «Add python.exe to PATH», иначе команды ниже не заработают.
2. Откройте командную строку (в Windows — «Терминал» или «cmd», в macOS — «Терминал») и выполните: pip install pyserial
3. Перейдите в папку проекта и запустите: python pvo_gui.py

Откроется окно пульта. В списке портов выберите тот же порт, что и в Arduino IDE, и нажмите «Подключить». Если Arduino IDE в этот момент открыт монитор порта — закройте его: порт может быть занят только одной программой одновременно.

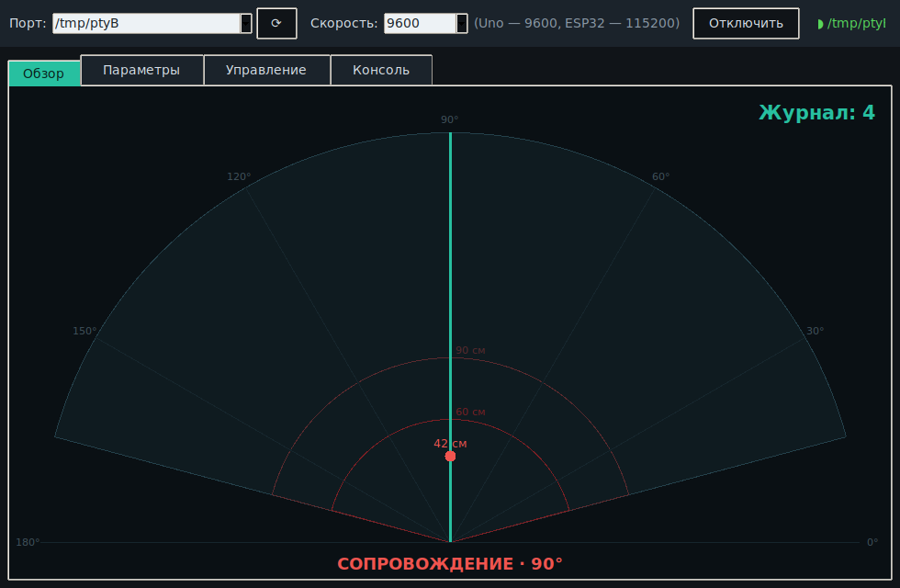
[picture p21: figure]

Рис. 14. Вкладка «Обзор»: живая картинка того, что видит турель

### Если посылка ещё едет — есть демо-режим

В списке портов есть строчки «ДЕМО: Uno» и «ДЕМО: ESP32». Выберите любую — и пульт подключится к виртуальной турели, которая живёт внутри программы. Она патрулирует, ловит цели, отвечает на все команды и ведёт журнал. Это лучший способ заранее разобраться в интерфейсе и параметрах.

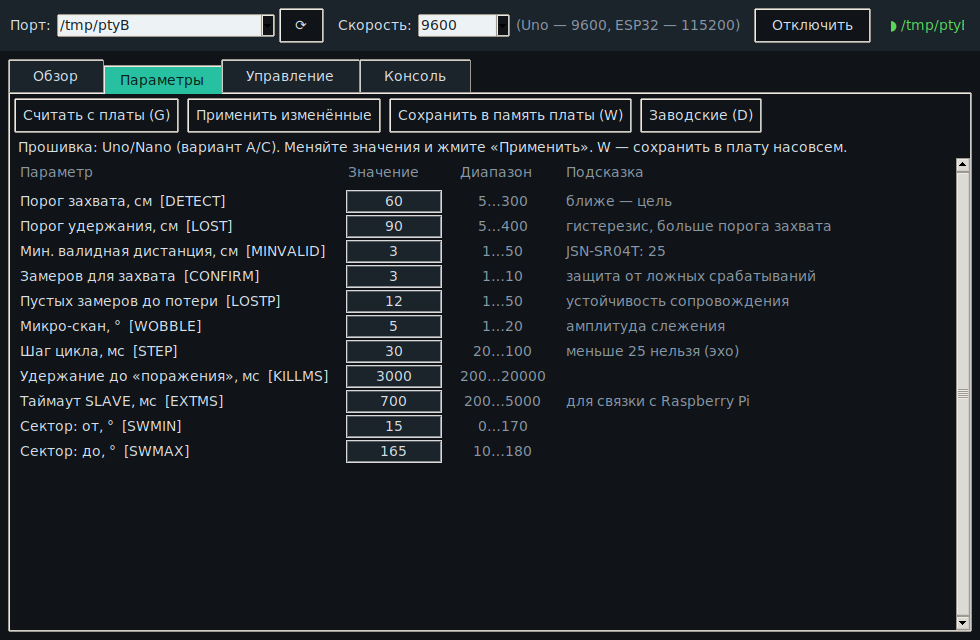
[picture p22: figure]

Рис. 15. Вкладка «Параметры»: все настройки турели без перепрошивки

Вкладок в пульте четыре. «Обзор» показывает, что видит турель, и ведёт журнал поражений. «Параметры» позволяет менять настройки: изменили значение, нажали «Применить изменённые» — турель начала вести себя иначе прямо сейчас. «Управление» — ручное наведение и тесты. «Консоль» — те же текстовые команды, что в мониторе порта, для любознательных.

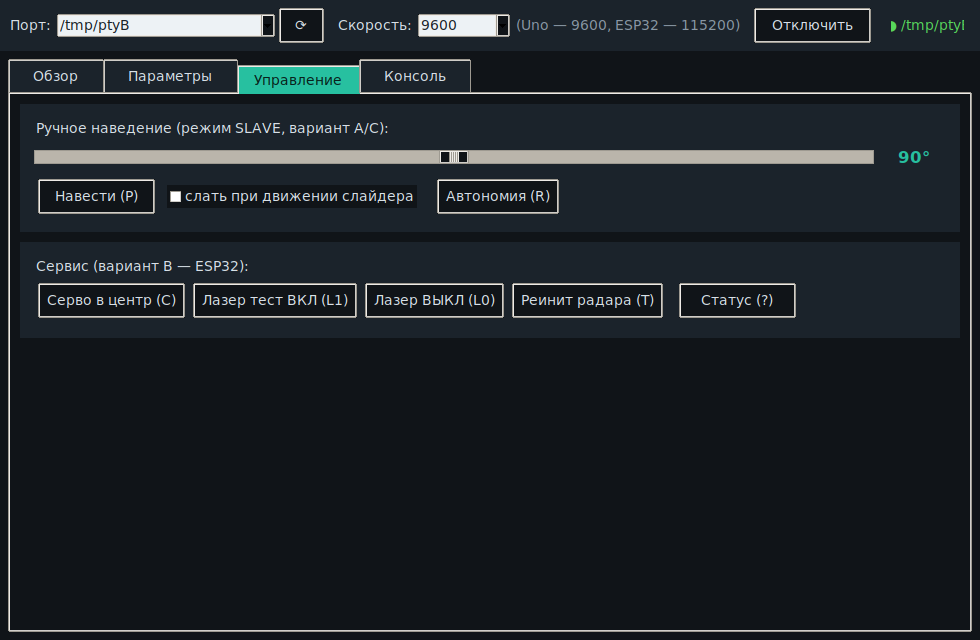
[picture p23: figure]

Рис. 16. Вкладка «Управление»: ручное наведение и проверка лазера

Два запомнить и не мучиться: кнопка «Сохранить в память платы (W)» записывает текущие настройки в плату насовсем — без неё после выключения питания вернутся прежние. А кнопка «Заводские (D)» возвращает всё к исходному состоянию, если вы окончательно запутались. Испортить турель настройками невозможно.

## 1.9. Настройки турели: каждая простыми словами

Турель ведёт себя так, как ей велят несколько чисел. Их можно менять на лету — из пульта или командой в мониторе порта — и сразу видеть результат. Ниже разобрана каждая настройка: что она значит, что вы почувствуете, если её тронуть, и что советую поставить.

Как менять настройку из монитора порта: напишите в строке ввода S ИМЯ ЗНАЧЕНИЕ и нажмите Enter. Например S DETECT 80 — захватывать цель до 80 сантиметров. Команда G покажет все текущие значения, W — сохранит их в плату, D — вернёт заводские.

DETECT — дальность захвата, см по умолчанию 60

Простыми словами. Ближе какого расстояния турель считает, что перед ней цель. Всё, что дальше, она игнорирует.

Что вы заметите. Чем больше значение, тем «дальнобойнее» турель — но тем чаще она будет реагировать на стену, шкаф или спинку стула, если те попали в сектор.

- Если турель ловит стену напротив — уменьшите до расстояния «чуть ближе, чем стена». Померьте рулеткой и вычтите 20 см;
- Если хотите, чтобы реагировала только на близко поднесённую руку — поставьте 30;
- Если нужна максимальная дальность — 150, но помните: дальше 1,5–2 м ультразвук работает неуверенно.

Совет. Начните с 60 и подгоняйте под свою комнату. Это первая настройка, которую стоит тронуть.

LOST — дальность потери, см по умолчанию 90

Простыми словами. Дальше какого расстояния турель считает, что цель ушла. Обратите внимание: это число больше, чем DETECT.

Что вы заметите. Разница между DETECT и LOST — это «запас», который не даёт турели терять цель из-за случайного скачка в измерениях. Если сделать их равными, турель начнёт «моргать»: захват-потеря-захват.

- Если цель постоянно теряется, хотя вы на месте, — увеличьте разрыв: DETECT 60, LOST 110;
- Если турель слишком долго держится за ушедшую цель — уменьшите LOST до 70.

Совет. Держите LOST примерно в полтора раза больше DETECT. Это правило работает почти всегда.

MINVALID — ближняя граница, см по умолчанию 3

Простыми словами. Всё, что ближе этого расстояния, считается не целью, а помехой — обычно это отражение от собственного крепления.

Что вы заметите. Если поставить слишком много, турель перестанет видеть близкие цели. Если слишком мало — начнёт ловить «призраков» из-за отражений от своей же конструкции.

- Если используете влагозащищённый датчик JSN-SR04T — обязательно поставьте 25: у него слепая зона больше;
- Если турель «захватывает» пустоту сразу после включения — увеличьте до 10–15.

Совет. Для обычного HC-SR04 оставьте 3 и не трогайте.

CONFIRM — сколько раз подтвердить по умолчанию 3

Простыми словами. Сколько замеров подряд должны показать цель, прежде чем турель поверит и захватит её.

Что вы заметите. Больше значение — спокойнее турель, но реагирует медленнее. Меньше — реагирует мгновенно, но чаще ошибается на случайных помехах.

- Если турель дёргается на пустом месте — поставьте 5–6;
- Если хотите быструю реакцию для демонстрации гостям — 2;
- Если в комнате есть вентилятор или занавеска на сквозняке — 6 и выше.

Совет. 3 — хороший баланс. Это ваш главный инструмент против ложных срабатываний.

LOSTP — сколько пустых замеров до отбоя по умолчанию 12

Простыми словами. Сколько раз подряд турель должна «не увидеть» цель, чтобы признать её потерянной и погасить лазер.

Что вы заметите. Большое значение — турель терпеливо ждёт возвращения цели, лазер горит дольше. Маленькое — мгновенно отпускает.

- Если цель мелькает за препятствием (например, вы ходите за спинкой стула) — увеличьте до 20;
- Если хотите, чтобы лазер гас сразу, как только вы убрали руку, — 6.

Совет. 12 замеров — это примерно треть секунды. Нормально для большинства сценариев.

WOBBLE — качание при сопровождении, ° по умолчанию 5

Простыми словами. Захватив цель, турель не стоит мёртво, а слегка покачивается вокруг точки захвата — так она замечает, что цель сместилась, и «идёт» за ней.

Что вы заметите. Больше значение — турель активнее ищет ушедшую цель, но выглядит более нервной, и лазерная точка гуляет. Меньше — точка стоит ровно, но за уходящей целью турель поспевает хуже.

- Если цель почти всегда неподвижна (демонстрация) — поставьте 2, точка будет стоять как влитая;
- Если нужно вести идущего человека — 8–10.

Совет. 5 — золотая середина. Если серво жужжит и греется на дежурстве, уменьшайте.

STEP — темп работы, мс по умолчанию 30

Простыми словами. Пауза между рабочими циклами: сколько миллисекунд турель «отдыхает» перед следующим замером и шагом поворота.

Что вы заметите. Меньше — турель шустрее и плавнее, но серво работает интенсивнее и греется. Больше — движение становится ступенчатым, зато всё тише и спокойнее.

- Если хочется тихой ночной работы — 50–60;
- Если нужна максимальная резвость — 20, ниже смысла нет: ультразвуку нужно время на эхо.

Совет. 30 подходит почти всем. Этот параметр трогают редко.

KILLMS — сколько удерживать до «поражения», мс по умолчанию 3000

Простыми словами. Сколько времени лазерная точка должна непрерывно держаться на цели, чтобы турель записала «поражение» в журнал.

Что вы заметите. По сути — правила игры. Три секунды удержания = одна засчитанная цель.

- Если показываете турель гостям и хочется частых «побед» — поставьте 1000;
- Если хотите, чтобы засчитывалось только настоящее долгое сопровождение, — 5000.

Совет. 3000 — разумно. Помните, что журнал хранится в плате и переживает выключение.

SWMIN и SWMAX — границы сектора, ° по умолчанию 15 и 165

Простыми словами. В каких пределах турель поворачивается при патрулировании. 90 — это «прямо по курсу», 0 — крайнее правое, 180 — крайнее левое положение.

Что вы заметите. Сектор определяет, что турель вообще способна увидеть. Заодно это главный инструмент безопасности: луч не выйдет за эти границы.

- Если турель стоит в углу и половину времени смотрит в стену — сузьте до 45 и 135;
- Если нужно охранять только один фланг — 90 и 165;
- Если хочется максимального обзора — 5 и 175, но у дешёвых серво на самых краях гудит редуктор.

Совет. Обязательно настройте сектор так, чтобы луч не смотрел в дверь, окно или туда, где ходят люди. Это важнее эстетики.

TRACKMAX и TRACKCD — предохранитель, мс по умолчанию 60000 и 10000

Простыми словами. TRACKMAX — сколько максимум турель может вести одну цель непрерывно. По истечении лимита она гасит лазер, отпускает цель и на время TRACKCD вообще ни за кем не гоняется.

Что вы заметите. Без этого предохранителя турель, зацепившаяся за колышущуюся штору или работающий вентилятор, будет светить лазером в одну точку часами.

- Если в комнате есть занавеска на сквозняке — уменьшите лимит до 30000 и паузу до 30000;
- Если турель работает при вас и вы хотите долгие демонстрации — 120000;
- Если нужно совсем отключить лимит — 0, но подумайте дважды.

Совет. Оставьте как есть. Это не про удобство, это про безопасность и ресурс серво.

## 1.10. Настроили — сохраните

Изменённые настройки живут в оперативной памяти платы и исчезнут при выключении питания. Чтобы они остались навсегда, нажмите в пульте «Сохранить в память платы (W)» либо отправьте в мониторе порта команду

W

Плата ответит «OK SAVED». Если совсем запутались и хочется начать с чистого листа — команда D вернёт заводские значения, а следующая W закрепит их.

## 1.11. Когда что-то не работает

Рис. 17. Порядок поиска неисправности

Прежде чем подозревать программу, вспомните: у новичка в девяти случаях из десяти виноват контакт, питание или кабель. Ниже — таблица самых частых бед в порядке убывания частоты.

Что видите | Почему так | Что делать
Плата не появляется в списке портов | кабель без линий данных; нет драйвера CH340; неисправный порт USB | смените кабель на заведомо хороший (от телефона, которым передаёте файлы), поставьте драйвер, попробуйте другой разъём
При загрузке ошибка «programmer is not responding» | выбран не тот порт или не та плата; открыт монитор порта; для Nano — не тот загрузчик | проверьте меню «Инструменты», закройте монитор, попробуйте «ATmega328P (Old Bootloader)»
Серво дёргается, плата всё время перезагружается | серво питается от платы | подключите серво к отдельному блоку питания и соедините земли; поставьте конденсатор 1000 мкФ
В мониторе иероглифы | не та скорость | в правом нижнем углу монитора выберите 9600 бод
Датчик показывает всегда одно и то же | перепутаны TRIG и ECHO, или нет питания на датчике | поменяйте два провода местами; проверьте, что VCC датчика на «+», а GND на «−»
Турель ловит цель там, где никого нет | в секторе есть стена, шкаф или занавеска | уменьшите DETECT, сузьте сектор SWMIN/SWMAX, увеличьте CONFIRM
Лазер не загорается | перепутаны ножки лазера или не тот пин | сигнальная ножка (S) — на D7; проверьте питание модуля
Буззер молчит | полярность или пассивный буззер без сигнала | переверните буззер; попробуйте другой
Всё работало, потом перестало | провод выскочил из макетки | пройдитесь пальцем по каждому проводу от начала до конца

Правило одного изменения. Меняйте по одной вещи за раз и смотрите результат. Если поменять сразу три — вы не поймёте, что помогло. Полезно вести короткий список: «сделал то-то → стало так-то». Это звучит занудно ровно до первого случая, когда вы полчаса ищете, что же сломали.

# Часть 2. Турель «как в видео» (вариант B)

Вариант A научил главному. Теперь сделаем ту самую турель из ролика: с настоящим радаром вместо ультразвука, с двумя осями поворота (влево-вправо и вверх-вниз) и с веб-панелью, которая открывается в браузере телефона. Дальность вырастет до 4–6 метров, и турель научится видеть до трёх целей сразу.

Сначала соберите вариант A. Серьёзно. Здесь всё то же самое, только деталей больше, и если что-то пойдёт не так, вы должны уже уметь отличать проблему с питанием от проблемы с прошивкой. Вариант A остаётся собранным — детали из него не нужны.

## 2.1. Что докупить

Что искать | Сколько | Цена | На что обратить внимание
ESP32 DevKit V1 (WROOM-32, 30 ножек) | 1 | ~550 ₽ | берите с распаянными гребёнками; USB-чип CP2102 или CH340
Радар HLK-LD2450 | 1 | ~800 ₽ | именно LD2450 или Ai-Thinker RD-03D. LD2410 НЕ подойдёт: он не выдаёт координаты
Серво MG90S | 2 | ~230 ₽ | две штуки: одна на поворот, вторая на наклон
Кронштейн pan-tilt под SG90/MG90S | 1 | ~300 ₽ | готовый комплект с винтами; можно напечатать на 3D-принтере (папка 3d/)
Транзистор 2N2222 (или BC337) | 2 | ~10 ₽ | второй про запас; нужен, потому что ESP32 выдаёт 3,3 В, а лазеру нужно 5 В
Резисторы 1 кОм | набор | ~60 ₽ | любой набор выводных резисторов
Кабель USB под ваш ESP32 | 1 | ~150 ₽ | micro-USB или USB-C — посмотрите на плату; снова: с линиями данных

## 2.2. Если модули пришли с гребёнками в пакетике

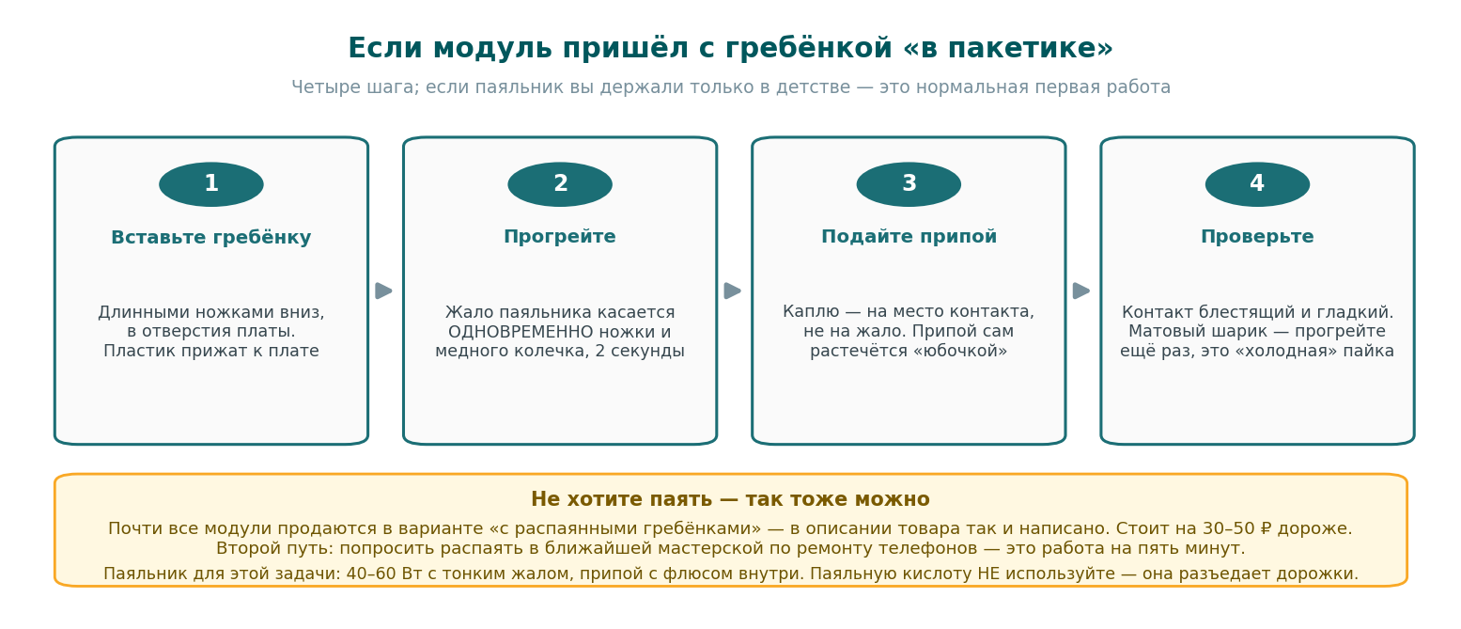
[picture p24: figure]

Рис. 18. Пайка гребёнок: четыре шага

Радары почти всегда приходят без распаянных контактов. Это не страшно: припаять восемь ножек — работа на десять минут, и это отличный первый опыт пайки. Если паяльника нет и заводить его не хочется, есть два обходных пути: искать товар с пометкой «с распаянными гребёнками» или отнести модуль в ближайшую мастерскую по ремонту телефонов — там это сделают за пять минут.

## 2.3. Учим Arduino IDE работать с ESP32

ESP32 — плата другого семейства, и IDE о ней сначала не знает. Научим её.

1. Меню Файл → Настройки. В поле «Дополнительные ссылки для Менеджера плат» вставьте:
2. https://raw.githubusercontent.com/espressif/arduino-esp32/gh-pages/package_esp32_index.json
3. Меню Инструменты → Плата → Менеджер плат. В поиске наберите esp32, найдите «esp32 by Espressif Systems» и нажмите «Установить». Это займёт несколько минут — скачивается около 200 МБ.
4. После установки в меню Инструменты → Плата появится длинный список плат ESP32. Выберите «ESP32 Dev Module».
5. Установите библиотеку для серво: Инструменты → Управлять библиотеками, в поиске «ESP32Servo», установить.

Если при загрузке появляется «Connecting…….» и ничего не происходит: на плате ESP32 есть кнопка BOOT. Нажмите и удерживайте её в момент, когда появится эта надпись, — загрузка пойдёт. Так устроены многие дешёвые платы.

## 2.4. Что такое транзистор и зачем он здесь


Рис. 19. Транзисторный ключ для лазера

Проблема простая: лазерному модулю для нормальной яркости нужно 5 вольт, а ножки ESP32 выдают 3,3. Прямое подключение даст тусклую точку, а попытка подать 5 вольт обратно в ножку платы её повредит.

Решение — транзистор. Думайте о нём как о реле без движущихся частей: слабый сигнал с платы «нажимает кнопку», а через саму кнопку течёт ток от пятивольтовой шины к лазеру. У транзистора три ноги: база (управление), коллектор и эмиттер. Схема такая: ножка GPIO23 платы → резистор 1 кОм → база; эмиттер → на землю; коллектор → на минус лазера; плюс лазера → на шину 5 В.

Резистор обязателен. Без него ножка платы отдаёт слишком большой ток в базу и может выгореть. Один килоом — стандартное значение, ошибиться сложно.

## 2.4a. Как радар видит цель

Ультразвуковой датчик из варианта A работал как эхолот: пискнул, дождался эха, посчитал расстояние. Радар устроен иначе и умеет больше.

Он непрерывно излучает радиоволну частотой 24 гигагерца — примерно как у автомобильных систем помощи водителю. Отражённая от предмета волна возвращается слегка изменённой: если предмет двигался, частота смещается (тот самый эффект Доплера, из-за которого сирена приближающейся машины звучит выше). По задержке возврата модуль считает дальность, по нескольким антеннам — направление, а по смещению частоты — скорость.

Поэтому радар отдаёт не «расстояние до чего-то», а сразу координаты: цель номер один находится в 78 сантиметрах левее и в 171 сантиметре впереди, движется со скоростью 16 сантиметров в секунду. Турели остаётся пересчитать эти координаты в углы поворота — этим и занимается прошивка.


Рис. 19а. Система координат радара: X — вбок, Y — вперёд

Чего радар не умеет. Он спроектирован для отслеживания людей, поэтому его собственная обработка отбрасывает всё, что меньше человека, и всё неподвижное. Комара он не увидит никогда — не потому, что «плохой», а потому, что так задумано его производителем. Именно поэтому в вариантах C и D появляется камера.

## 2.5. Сборка


Рис. 20. Схема соединений варианта B

Что подключаем | Куда на ESP32 | Примечание
Радар, вывод TX | GPIO16 | провод «от радара к плате»
Радар, вывод RX | GPIO17 | провод «от платы к радару»
Радар, питание | 5 В и GND | радар питается от 5 В, но общается уровнями 3,3 В — это нормально
Серво поворота (PAN) | GPIO26 | питание — от блока питания, не от платы
Серво наклона (TILT) | GPIO27 | то же самое
Лазер (через транзистор) | GPIO23 | см. раздел 2.4
Буззер | GPIO19 | плюсом на пин, минусом на землю

Рис. 21. Сборка механики pan-tilt

Механику собирайте по инструкции к кронштейну; главное правило — сначала прошить плату и дать серво встать в центральные положения, и только потом окончательно затягивать качалки «прямо по курсу». Иначе турель будет смотреть криво, и это не лечится настройками.

## 2.6. Прошивка и первый запуск

1. Откройте файл pvo_esp32/pvo_esp32.ino в Arduino IDE.
2. Проверьте: плата «ESP32 Dev Module», порт — ваш.
3. Нажмите «Загрузка» (при надписи «Connecting…» удерживайте BOOT).
4. Откройте монитор порта и выберите скорость 115200 бод — у ESP32 она другая, чем у Arduino.
5. Пройдитесь перед турелью в двух-трёх метрах. В мониторе появится «ЦЕЛЬ ЗАХВАЧЕНА: x=… мм, y=… мм» и загорится лазер.


Рис. 22. Вывод варианта B: радар сообщает координаты цели

Полезные команды в мониторе порта: C — поставить серво в центр на восемь секунд (удобно для юстировки), L1 и L0 — включить и выключить лазер для проверки, T — переинициализировать радар, ? — показать состояние.

## 2.7. Веб-панель: турель в браузере телефона


Рис. 23. Веб-панель, открытая в телефоне

Прошивка ESP32 умеет раздавать собственную сеть Wi-Fi. Найдите в списке сетей на телефоне «PVO-Komar», подключитесь с паролем komar12345 и откройте в браузере адрес 192.168.4.1. Вы увидите живой радарный экран, все настройки и кнопки управления.

Смените пароль. Он написан прямо в начале файла прошивки, в строке с WIFI_PASS. Замените на свой и перепрошейте — иначе к вашей турели сможет подключиться любой сосед.

## 2.8. Настройки варианта B простыми словами

Здесь настроек больше, потому что осей две, а радар даёт координаты. Разберём по группам. Общий принцип тот же: меняете, смотрите, сохраняете командой W.

### Куда турель смотрит

PANC и TILTC — центры осей, ° по умолчанию 90 и 90

Простыми словами. Какое положение серво считать «прямо по курсу» и «по горизонту». Механика никогда не собирается идеально ровно — эти числа компенсируют перекос.

Что вы заметите. Если турель смотрит чуть вбок или вниз, когда должна смотреть прямо, — дело в них.

- Если турель косит вправо на пять градусов — уменьшите PANC на 5;
- Если смотрит в пол — увеличьте TILTC на несколько единиц.

Совет. Сначала выровняйте механику руками, командой C поставив серво в центр, и только потом подгоняйте эти числа.

PANMIN / PANMAX и TILTMIN / TILTMAX — пределы поворота, ° по умолчанию 15/165 и 60/120

Простыми словами. За эти границы турель не выйдет никогда, что бы ни увидела.

Что вы заметите. Это ваша страховка: луч физически не сможет уйти в окно или в лицо сидящему человеку.

- Если турель задевает провода в крайних положениях — сузьте границы;
- Если не нужно, чтобы луч поднимался выше стола, — уменьшите TILTMAX.

Совет. Настройте так, чтобы в любой точке диапазона луч упирался в стену или пол.

PANINV и TILTINV — инверсия направления по умолчанию 0 и 0

Простыми словами. Переключатель «турель крутится не в ту сторону». Ноль — нормально, единица — наоборот.

Что вы заметите. Если при движении цели вправо турель поворачивается влево — включите инверсию по этой оси.

- Если собрали кронштейн зеркально — просто поставьте 1 вместо 0, перепаивать ничего не нужно.

Совет. Проверяется за десять секунд: пройдите слева направо и посмотрите, куда повернётся турель.

### Что считать целью

MINR и MAXR — рабочая дальность, мм по умолчанию 300 и 4000

Простыми словами. Ближе MINR и дальше MAXR цели игнорируются. Значения в миллиметрах: 4000 — это четыре метра.

Что вы заметите. Главный инструмент против ложных целей: сузив зону, вы отсекаете движение в дверном проёме и за окном.

- Если радар ловит соседей за стеной — уменьшите MAXR до 2500;
- Если нужна работа по всей комнате — 6000, но точность у края падает.

Совет. Померьте расстояние до стены и поставьте MAXR чуть меньше.

MAXAZ — ширина сектора, ±° по умолчанию 60

Простыми словами. Насколько широко вправо и влево от «прямо» турель принимает цели.

Что вы заметите. Уже сектор — меньше ложных срабатываний и быстрее реакция.

- Если турель в углу комнаты — 30–40 хватит;
- Если нужен максимальный обзор — 60, это предел радара.

Совет. Начните с 45, если комната обычная.

CONFIRM — кадров для захвата по умолчанию 5

Простыми словами. Сколько раз подряд радар должен показать цель, прежде чем турель её захватит.

Что вы заметите. Так же, как в варианте A: больше — спокойнее, меньше — быстрее.

- Если ложные захваты от вентилятора — 8;
- Если хочется мгновенной реакции — 3.

Совет. 5 кадров при частоте радара — это примерно полсекунды.

### Как турель движется

ALPHA — плавность, ×100 по умолчанию 35

Простыми словами. Насколько резко турель отрабатывает новую координату цели. Число передаётся умноженным на сто: 35 означает 0,35.

Что вы заметите. Маленькое значение — движение вязкое и плавное, лазер не дрожит, но за быстрой целью турель не успевает. Большое — мгновенная реакция и заметное дрожание.

- Если точка лазера дрожит на неподвижной цели — уменьшите до 20;
- Если турель вяло тащится за идущим человеком — увеличьте до 50.

Совет. 35 — хорошая отправная точка. Меняйте шагами по 5–10.

SLEW — максимальная скорость, °/шаг по умолчанию 6

Простыми словами. Ограничение: больше этого количества градусов за один шаг турель не повернётся.

Что вы заметите. Защищает механику от рывков, когда цель «прыгает» через всю комнату.

- Если серво щёлкают при резких перебросах — уменьшите до 3;
- Если турель не успевает за быстрой целью — 10.

Совет. 6 — комфортно для MG90S. Дешёвые SG90 лучше держать на 4.

PATROL и PSPEED — патрулирование по умолчанию 1 и 35

Простыми словами. Ходит ли турель по сектору, когда целей нет (1 — да, 0 — стоять на месте), и с какой скоростью.

Что вы заметите. Патруль выглядит эффектно, но серво постоянно работают и могут гудеть.

- Если турель стоит в спальне и мешает спать — поставьте PATROL 0;
- Если хочется медленного «обзора» — PSPEED 15.

Совет. Ночью выключайте патруль: серво живут дольше, а вы спите спокойнее.

ATILT, TURH, TGTH — автоматический наклон по умолчанию 1, 750, 1100

Простыми словами. Радар говорит, на каком расстоянии цель, но не говорит, на какой высоте. Прошивка вычисляет наклон сама: зная высоту турели над полом (TURH) и предполагаемую высоту цели (TGTH), она поднимает или опускает ствол в зависимости от дальности. ATILT включает эту автоматику.

Что вы заметите. Если наклон работает верно, лазер ложится на цель и вблизи, и вдали. Если числа неверны, вблизи луч будет бить в пол, а вдали — в потолок (или наоборот).

- Если турель стоит на столе высотой 75 см и ловит людей — оставьте как есть;
- Если турель на полу, а цели — люди: TURH 100, TGTH 1100;
- Если хотите отключить автоматику и держать ствол горизонтально — ATILT 0.

Совет. Числа в миллиметрах. Померьте рулеткой реальную высоту турели — этого достаточно.

LOSTMS — сколько ждать пропавшую цель, мс по умолчанию 700

Простыми словами. Если радар перестал видеть цель, турель ждёт столько времени, прежде чем погасить лазер.

Что вы заметите. Больше — турель терпеливее к морганиям радара, лазер горит дольше. Меньше — мгновенно отпускает.

- Если цель ненадолго заходит за препятствие — 1200;
- Если хотите, чтобы лазер гас сразу, — 400.

Совет. 700 мс — примерно семь кадров радара. Хороший компромисс.

Настройки KILLMS, TRACKMAX и TRACKCD работают точно так же, как в варианте A, — смотрите их описания в разделе 1.9.

## 2.9. Частые беды варианта B

Что видите | Почему | Что делать
«РАДАР МОЛЧИТ» в мониторе | перепутаны TX и RX, нет питания 5 В, не пропаяны гребёнки | поменяйте два провода местами; проверьте питание; прозвоните пайку
Радар видит цели, турель не двигается | серво без питания или не тот пин | проверьте блок питания и общую землю
Турель крутится в обратную сторону | зеркальная сборка кронштейна | S PANINV 1 (или TILTINV)
Лазер тусклый | подключён напрямую к 3,3 В | соберите транзисторный ключ (раздел 2.4)
Не подключается веб-панель | телефон ушёл в мобильный интернет | в настройках Wi-Fi отключите «автопереход на мобильные данные»
При загрузке «Connecting…» | плате нужен ручной вход в режим прошивки | удерживайте кнопку BOOT

# Часть 3. Турель со зрением (вариант C)

Ультразвук и радар видят только крупные цели. Чтобы заметить муху или комара, нужен принципиально другой датчик — камера. В этой части мы добавим к турели маленький компьютер Raspberry Pi, который будет смотреть камерой и подсказывать турели, куда наводиться.


Рис. 24. Arduino и Raspberry Pi — разные инструменты для разных задач

## 3.1. Зачем нужен второй компьютер

Arduino отлично крутит серво: она включается мгновенно и делает ровно одно дело. Но распознать движущуюся точку в видеопотоке она не может — не хватает вычислительной мощности. Raspberry Pi, наоборот, это полноценный компьютер с Linux, которому анализ картинки по силам, зато точно управлять серво он не умеет — операционная система может «задуматься» на десяток миллисекунд.

Поэтому мы соединяем их вместе обычным USB-кабелем: Pi смотрит и говорит «цель на 20 градусов левее», Arduino поворачивает и светит. Если Pi выключить, турель просто продолжит работать сама по себе, как в варианте A. Это удобно: зрение можно добавить и убрать в любой момент.

## 3.2. Что купить

Что искать | Цена | Примечание
Raspberry Pi 4 (2 или 4 ГБ) либо Pi 5 | ~6 500 ₽ | Pi Zero 2 W дешевле (~3 000 ₽), но заметно медленнее — картинку придётся уменьшать
Карта памяти microSD 32 ГБ, класс A1/U3 | ~500 ₽ | дешёвая карта — главная причина «Pi глючит»; не экономьте здесь
Блок питания USB-C 5 В / 3 А | ~900 ₽ | фирменный или качественный: Pi очень чувствительна к просадкам
Камера: USB-вебка 720p+ или модуль Camera v2/v3 | ~900–4 000 ₽ | вебка проще (воткнул и работает), модуль лучше видит в темноте
Корпус с охлаждением или радиаторы | ~500 ₽ | не обязательно, но Pi 4 греется

## 3.3. Готовим карту памяти

1. Скачайте на компьютер программу Raspberry Pi Imager с сайта raspberrypi.com — она бесплатная и есть для всех систем.
2. Вставьте карту памяти в компьютер (понадобится картридер).
3. В Imager выберите: устройство — ваша модель Pi; систему — «Raspberry Pi OS (64-bit)»; носитель — вашу карту.
4. Нажмите шестерёнку (настройки) и сразу задайте: имя пользователя и пароль, вашу сеть Wi-Fi с паролем, и включите SSH. Это избавит вас от необходимости подключать к Pi монитор и клавиатуру.
5. Нажмите «Записать» и подождите. Потом вставьте карту в Pi и включите питание — первая загрузка занимает пару минут.

## 3.4. Терминал: не страшно, а удобно

Дальше придётся работать с командной строкой. Это просто окно, куда вы пишете команды текстом. Пугаться нечего: команд нам понадобится меньше десяти, и все они ниже.

Подключитесь к Pi с основного компьютера. В Windows откройте «Терминал» или PowerShell, в macOS — «Терминал», и наберите (подставив своё имя пользователя):

ssh pi@raspberrypi.local

Согласитесь с вопросом про ключ (наберите yes), введите пароль — и вы внутри. Пароль при вводе не отображается, это нормально, просто печатайте вслепую.

Команда | Что делает
ls | показать, какие файлы есть в текущей папке
cd имя_папки | перейти в папку; cd .. — на уровень выше
pwd | показать, где вы сейчас находитесь
nano файл | открыть файл в простом редакторе (выход — Ctrl+X)
sudo команда | выполнить команду с правами администратора (спросит пароль)
sudo apt update && sudo apt full-upgrade | обновить систему; делается один раз после установки
python3 файл.py | запустить программу на Python
Ctrl+C | остановить запущенную программу
reboot / sudo shutdown -h now | перезагрузить / выключить Pi

Никогда не выдёргивайте питание из работающей Pi. Это компьютер с файловой системой: внезапное отключение может испортить карту памяти, и придётся записывать её заново. Выключайте командой sudo shutdown -h now и ждите, пока погаснет зелёный светодиод.

## 3.5. Устанавливаем программы

Выполните по очереди (каждую строку — отдельно, дождавшись окончания):

sudo apt update && sudo apt full-upgrade -y

sudo apt install python3-opencv python3-serial python3-numpy -y

sudo usermod -aG dialout $USER

Первая команда обновляет систему, вторая ставит библиотеку компьютерного зрения OpenCV и работу с портом, третья даёт вашему пользователю право обращаться к USB-порту турели. После третьей нужно перезагрузиться: sudo reboot.

Теперь скопируйте на Pi файл pvo_vision.py. Проще всего — с основного компьютера командой (из папки с файлом):

scp pvo_vision.py pi@raspberrypi.local:~/

Если scp пугает — просто скопируйте файл на флешку и перенесите руками, это ничем не хуже.

## 3.6. Соединяем и запускаем


Рис. 25. Как расставить камеру, турель и Pi

1. Прошейте в турель (Arduino из варианта A) полную прошивку pvo.ino — она умеет принимать целеуказание. Простая pvo_a_simple.ino для этого не годится.
2. Соедините Pi и Arduino обычным USB-кабелем.
3. Поставьте камеру рядом с турелью, объективом в ту же сторону. Важно: камера НЕ на качалке, она стоит неподвижно.
4. Запустите на Pi: python3 pvo_vision.py --display — если к Pi подключён монитор, увидите окно с картинкой и рамкой вокруг цели.
5. Помашите рукой перед камерой: турель повернётся вслед. Остановка — Ctrl+C, турель сама вернётся к самостоятельной работе.

Чтобы зрение сработало на мелочи, нужен контраст. Комар на белой стене при хорошем свете — реально. Комар на фоне ковра в полумраке — нет. Это ограничение физики, а не программы.

## 3.7. Настройки зрения простыми словами

Они живут в начале файла pvo_vision.py, в блоке CONFIG. Открыть файл для правки: nano pvo_vision.py, сохранить — Ctrl+O и Enter, выйти — Ctrl+X.

FOV_H_DEG — угол обзора камеры, ° по умолчанию 60

Простыми словами. Насколько широко видит ваша камера по горизонтали. Это паспортная характеристика, у обычных вебок 55–70 градусов.

Что вы заметите. Если значение неверное, турель будет мазать тем сильнее, чем ближе цель к краю кадра: в центре наводится точно, по краям — мимо.

- Если цель в центре — попадание, по краям — промах: значит, FOV указан неверно;
- Если точное значение можно найти в описании камеры или подобрать: наводитесь на цель у самого края и правьте число, пока не совпадёт.

Совет. Это самый важный параметр варианта C. Потратьте на него пять минут — окупится.

MIN_AREA_PX — минимальный размер цели, пикселей по умолчанию 25

Простыми словами. Всё, что меньше этого пятнышка в кадре, считается шумом и игнорируется.

Что вы заметите. Маленькое значение — турель реагирует на мух и пылинки, но и на шум матрицы. Большое — видит только крупное.

- Если хотите охотиться на мелочь — 8–15 и хороший свет;
- Если турель дёргается от «мусора» в кадре — 40–60.

Совет. Подбирайте с включённым окном (--display): видно, что именно детектор считает целью.

BG_THRESHOLD — чувствительность к движению по умолчанию 28

Простыми словами. Насколько сильно пиксель должен измениться, чтобы считаться движением.

Что вы заметите. Меньше — чувствительнее (и больше ложных срабатываний на мерцании ламп). Больше — спокойнее, но мелочь может потеряться.

- Если мерцает люминесцентная лампа — увеличьте до 40;
- Если цель слабо контрастирует с фоном — уменьшите до 16–20.

Совет. Меняйте вместе с MIN_AREA_PX: они работают в паре.

SEND_HZ — как часто командовать турелью по умолчанию 15

Простыми словами. Сколько раз в секунду Pi отправляет турели новый угол.

Что вы заметите. Больше — плавнее ведение, но серво работают напряжённее. Меньше — экономнее, но движение рывками.

- Если серво гудят и греются — 8–10;
- Если цель быстрая, турель отстаёт — 20.

Совет. 15 — комфортное значение для большинства связок.

FRAME_W и FRAME_H — размер кадра по умолчанию 640 и 480

Простыми словами. Разрешение картинки, с которой работает программа. Не путать с разрешением камеры: программа сама уменьшает кадр до этого размера.

Что вы заметите. Больше кадр — виднее мелочь, но Pi считает медленнее, и турель реагирует с задержкой. Меньше — быстро, но мелкие цели теряются.

- Если у вас Pi Zero 2 W и всё тормозит — поставьте 320 и 240;
- Если нужна максимальная чувствительность к мелочи и есть Pi 5 — 800 и 600.

Совет. 640×480 — золотая середина. Скорость в кадрах в секунду программа печатает сама, ориентируйтесь на неё: ниже 8 — уже некомфортно.

CAMERA_INDEX — какая камера по умолчанию 0

Простыми словами. Номер камеры в системе. Если камера одна, это ноль.

Что вы заметите. Если в системе есть встроенная камера (например, у ноутбука) или подключены две вебки, программа может взять не ту.

- Если видите картинку не с той камеры — попробуйте 1, затем 2;
- Если используете модуль камеры Raspberry Pi (шлейф, а не USB) — запускайте с ключом --picamera.

Совет. Проще всего проверить с ключом --display: сразу видно, чью картинку взяли.

Полезные ключи запуска: --display показывает окно с картинкой и рамкой (незаменимо при настройке), --dry-run гоняет зрение без турели и печатает команды в консоль (удобно, пока турель не собрана), --save-hits сохраняет кадры захватов в папку hits — потом интересно пересматривать.

## 3.8. Чтобы зрение включалось само

Чтобы не запускать программу вручную после каждой перезагрузки, оформим её как службу. В проекте есть готовый файл — не нужно ничего печатать:

sudo cp systemd/pvo.service /etc/systemd/system/

sudo systemctl daemon-reload

sudo systemctl enable --now pvo.service

Посмотреть, что происходит: journalctl -u pvo -f (выход — Ctrl+C). Остановить: sudo systemctl stop pvo.service. Внутри файла службы есть комментарии — если у вас другое имя пользователя или путь, поправьте их редактором nano.

# Часть 4. Слияние и ночная охота (вариант D)

Финальная ступень. Здесь камера переезжает с подоконника на саму турель и становится прицелом, радар остаётся дальнобойным «взглядом», а инфракрасная подсветка открывает охоту в темноте. Это надстройка над вариантом B, использующая компьютер из варианта C.

Рис. 26. Как работает слияние: радар будит зрение, зрение ведёт точно

## 4.1. Идея простыми словами

У радара и камеры разные сильные стороны. Радар видит далеко, сквозь темноту, но только крупное. Камера видит мелочь, но лишь там, куда смотрит, и требует света. Логично поручить каждому своё: радар замечает цель за четыре метра и грубо доворачивает турель, после чего просыпается камера, находит цель уже около центра кадра и ведёт её точно.

А ночью, когда включается инфракрасная подсветка, камера начинает видеть то, чего радар не увидит никогда: мошку в луче на тёмном фоне превращается в яркую точку. Тогда зрение работает само по себе, без всякого радара.

## 4.2. Что докупить

Что искать | Цена | Примечание
Камера БЕЗ ИК-фильтра | 0–2 500 ₽ | Raspberry Pi Camera NoIR — сразу такая. Или снять фильтр с уже имеющейся вебки
ИК-модуль подсветки 850 нм | ~250 ₽ | готовая плата от камер видеонаблюдения или 6 отдельных диодов 5 мм
MOSFET 2N7000 (или тот же 2N2222) | ~20 ₽ | если подсветка мощная (больше 150 мА) — нужен MOSFET
Держатель камеры | печать или пластик | модель есть в папке 3d/ — панель с кольцом под диоды и люлька


Рис. 27. Проверка камеры пультом от телевизора — 10 секунд

## 4.3. Подключаем подсветку


Рис. 28. Ключ ИК-подсветки и размещение узлов на голове турели

Схема ровно такая же, как у лазера в разделе 2.4, только вместо GPIO23 используется GPIO18: ножка платы → резистор 1 кОм → база транзистора; эмиттер на землю; коллектор на минус ИК-модуля; плюс модуля — на шину 5 вольт от блока питания.

Проверка: наберите в мониторе порта команду I1. На экране камеры без фильтра диоды вспыхнут ярко-сиреневым, а глазом вы увидите лишь едва заметное тёмно-красное свечение. Команда I0 гасит.

Питание подсветки — только от блока питания. ИК-плата на 48 диодов потребляет до половины ампера. От платы такое брать нельзя. И повторим главное: только светодиоды, никаких ИК-лазеров — невидимый луч не вызывает моргательного рефлекса.

## 4.4. Пристрелка: без неё турель будет мазать

Это самый важный раздел части. Камера закреплена рядом с лазером, а не на его месте — значит, луч светит не точно в центр кадра, а немного в сторону. Если это не учесть, система будет аккуратно и стабильно ставить цель мимо луча — ровно на величину смещения.

Лечится за минуту, программно. Наведите турель на матовую стену в полутора-двух метрах (команда C ставит серво в центр), притените комнату и выполните на Pi:

python3 pvo_fusion.py --calibrate

Скрипт сам зажжёт лазер, найдёт его пятно в кадре, усреднит десяток снимков и запомнит эту точку. Дальше все поправки будут считаться от неё. Результат сохраняется в файл pvo_aim.json и подхватывается при каждом запуске.

Что написал скрипт | Что это значит | Что делать
«Точка лазера: +34, −12 пикс» | всё получилось | ничего, работайте
«НЕ НАШЁЛ точку лазера» | пятна в кадре не видно | притените комнату, подойдите к стене ближе, проверьте, что лазер горит
«Смещение большое» | камера стоит слишком далеко от лазера | поправьте крепление — иначе цель у края кадра будет недосягаема
«пристрелки нет» | калибровка не выполнялась | выполните --calibrate: без этого турель мажет

Повторяйте пристрелку каждый раз, когда сдвинули камеру, сменили объектив или разрешение кадра. Это как пристрелка настоящего прицела: сбилось крепление — сбилась и точка попадания.

## 4.5. Запуск и ночная охота

1. Скопируйте на Pi оба файла: pvo_fusion.py и pvo_vision.py — второй нужен первому.
2. Соедините Pi и ESP32 кабелем USB.
3. Дневной режим: python3 pvo_fusion.py --display — увидите жёлтое перекрестье (пристрелянная точка лазера) и рамку на цели.
4. Ночной режим: python3 pvo_fusion.py --detector bright в затемнённой комнате с тёмным однородным фоном.
5. Автозапуск: готовый файл systemd/pvo-fusion.service, ставится так же, как в разделе 3.8.

Для ночной охоты важна сцена: тёмный фон (тёмная стена, лист чёрного картона), выключенный свет, никаких ламп и окон в кадре. Каждая яркая точка в кадре — потенциальная ложная цель. Реальная дальность подсветки на 48 диодов — от полуметра до двух метров.

## 4.6. Настройки слияния

DETECTOR — чем ищем цель по умолчанию motion

Простыми словами. Два способа: motion ищет любое движение (годится днём), bright ищет яркие точки (ночная охота с подсветкой).

Что вы заметите. Днём bright бесполезен — солнце и блики дают сплошные «яркие точки». Ночью motion почти ничего не видит.

- Если охотитесь днём по крупным целям — motion;
- Если ночью с подсветкой по мелочи — bright.

Совет. Начните с motion и убедитесь, что связка вообще работает. Потом переходите на ночной режим.

BRIGHT_THRESH — порог яркости по умолчанию 200

Простыми словами. Насколько ярким должен быть пиксель, чтобы считаться целью в ночном режиме. Шкала от 0 (чёрный) до 255 (белый).

Что вы заметите. Слишком высокий порог — цель не видна; слишком низкий — «целями» становятся блики и шум.

- Если подсветка слабая или цель далеко — 160–180;
- Если в кадр попадают лампы или окно — 220–240.

Совет. Подбирайте с окном --display: пустой фон должен молчать, а пролетающая мошка — загораться.

DEADZONE_DEG — мёртвая зона, ° по умолчанию 0,4

Простыми словами. Если цель уже почти точно под лучом, турель не дёргается: поправка меньше этого угла считается нулевой.

Что вы заметите. Без мёртвой зоны серво постоянно микроскопически подрабатывают, жужжат и греются.

- Если серво заметно дрожат на неподвижной цели — увеличьте до 0,6–0,8;
- Если нужна максимальная точность по мишени — 0,2.

Совет. 0,4 градуса — это примерно четыре пикселя в кадре: меньше, чем точность самой пристрелки.

ROI — где искать цель в кадре по умолчанию 0,7

Простыми словами. Доля центральной части кадра, в которой бодрствующее зрение ищет цель. Радар уже повернул турель, поэтому цель почти наверняка в центре, а края кадра дают только ложные срабатывания.

Что вы заметите. Уже область — меньше мусора, но если радар довернул грубо, цель может оказаться за её пределами, и зрение «проснётся и ничего не найдёт».

- Если зрение просыпается, но цель не находит — расширьте до 0,9 или 1,0;
- Если фон беспокойный, много ложных — сузьте до 0,5.

Совет. 0,7 подходит большинству сборок. Если сомневаетесь, начните с 1,0 и сужайте.

WAKE_EVERY — экономия в дрёме по умолчанию 8

Простыми словами. Пока радар молчит, зрение обрабатывает не каждый кадр, а каждый восьмой. Так Raspberry Pi почти не греется на дежурстве.

Что вы заметите. Меньше значение — мелочь замечается быстрее, но процессор всё время загружен. Больше — экономнее, но реакция на мошку чуть медленнее.

- Если у вас Pi Zero 2 W — 12–16;
- Если мощный компьютер и хочется мгновенной реакции — 2–4.

Совет. 8 при пятнадцати кадрах в секунду — это проверка примерно два раза в секунду. Комар за это время далеко не улетит.

IRAUTO — автоматика подсветки по умолчанию 1

Простыми словами. Включать ли подсветку самостоятельно в момент захвата цели (1) или только вручную командами I1 и I0 (0).

Что вы заметите. С автоматикой ИК горит только во время сопровождения — не светит зря и не привлекает внимания.

- Если подсветки нет вовсе — можно оставить 1, пин просто щёлкает вхолостую;
- Если хотите держать подсветку под ручным контролем — 0.

Совет. Оставьте 1: это и экономия, и меньше ИК-света в комнате.

VISTO — терпение прошивки, мс по умолчанию 700

Простыми словами. Сколько прошивка ждёт подсказок от зрения, прежде чем решить, что зрение потеряло цель, и вернуться к радару.

Что вы заметите. Если компьютер медленный и кадры идут редко, прошивка будет постоянно «отбирать» цель у зрения.

- Если у вас Pi Zero 2 W — поставьте 1200–1500;
- Если мощная Pi 5 — можно 400, возврат к радару станет мгновенным.

Совет. Правило: VISTO должно быть в три-четыре раза больше паузы между кадрами. Скорость кадров скрипт печатает сам.

# Часть 5. Жизнь с турелью

## 5.0. Где поставить турель

Место решает больше, чем любые настройки. Хорошо поставленная турель работает без ложных срабатываний из коробки, плохо поставленная будет мучить вас неделю.

Правило | Почему
Ниже или выше уровня глаз сидящего человека | луч наводится сам, и вы не контролируете, куда он пойдёт. На уровне глаз ставить нельзя
Сектором в стену, а не в дверь или окно | за дверью ходят люди, за окном — соседи; и то и другое даёт ложные цели и лишний риск
Спиной к источникам движения | занавеска на сквозняке, вентилятор, работающий телевизор и аквариум — постоянные ложные цели
На устойчивом основании | серво при рывке способно сдвинуть лёгкую конструкцию; турель, съехавшая со стола, — грустное зрелище
Так, чтобы жгут не натягивался | провод, натянутый в крайнем положении, вырывает разъёмы и уводит наведение
Не в спальне, если включён патруль | серво тихо, но отчётливо жужжат; на ночь патруль лучше выключать (PATROL 0 или STEP 50)

Если в доме есть кот, считайте, что у вас появился профессиональный испытатель: он найдёт все слабые места конструкции за первый же вечер и будет смотреть прямо в лазер. Ограничьте сектор так, чтобы луч всегда упирался в пол или стену ниже кошачьего роста, и не оставляйте турель включённой без присмотра.

## 5.1. Методика настройки: как не запутаться

Настроек много, и соблазн крутить всё сразу велик. Есть порядок, который экономит часы.

1. Сначала механика. Поставьте серво в центр (команда C или «Серво в центр» в пульте) и закрепите всё «прямо по курсу». Ни один параметр не исправит криво приклеенный датчик.
2. Потом направления. Пройдите слева направо: турель должна повернуть вслед. Если наоборот — включите инверсию.
3. Потом зона. Ограничьте дальность и сектор так, чтобы турель не видела стену, дверь и окно. Большинство «ложных срабатываний» лечится здесь.
4. Потом пороги. Добейтесь уверенного захвата вашей типичной цели: DETECT и CONFIRM в варианте A, MINR/MAXR и CONFIRM в B.
5. В последнюю очередь характер. Плавность и скорость: WOBBLE в A, ALPHA и SLEW в B. Это косметика, её настраивают, когда всё остальное работает.
6. Сохраните. Команда W или кнопка «Сохранить в память платы».

Меняйте по одному параметру и небольшими шагами. Пороги — на 10–20 процентов, плавность — на 0,05–0,1. После каждого изменения посмотрите десять-двадцать секунд, как турель себя ведёт. Испортили всё — команда D вернёт заводские значения, это не страшно и делается за секунду.

## 5.2. Готовые профили под ситуацию

Ситуация | Вариант A | Вариант B
Стол, показать гостям | DETECT 40, KILLMS 1000, сектор 45–135 | MAXR 2000, ALPHA 50, KILLMS 1000
Комната, дежурство | по умолчанию | по умолчанию
Ночь, тишина | STEP 50 (меньше движений) | PATROL 0 (не патрулировать)
Много ложных целей | CONFIRM 6, DETECT меньше | CONFIRM 8, MAXR и MAXAZ меньше
Работа без присмотра | TRACKMAX 30000, TRACKCD 30000 | TRACKMAX 30000, TRACKCD 30000

## 5.3. Уход и обслуживание

- Раз в месяц протирайте «глаза» дальномера, линзу лазера и переднюю грань радара — пыль заметно снижает чувствительность.
- Проверяйте винты качалок: разболтавшийся крепёж даёт «пьяную» точку лазера, которую бесполезно лечить настройками.
- Следите, чтобы жгут проводов не натягивался в крайних положениях — это самая частая механическая поломка.
- Если серво гудят на дежурстве — выключите патрулирование или увеличьте паузу цикла. Меньше движения — дольше живёт редуктор.
- Счётчик загрузок в статусе — ваш индикатор здоровья питания: он должен расти только тогда, когда вы сами включаете турель.

## 5.4. Проверить всё, пока посылка едет

Ждать детали неделю и ничего не делать скучно. В проекте есть три способа поиграть с турелью без единой купленной детали.

- Демо-режим пульта. Запустите pvo_gui.py и выберите порт «ДЕМО: Uno» или «ДЕМО: ESP32». Внутри живёт виртуальная турель: патрулирует, ловит цели, отвечает на команды. Отличный способ заранее разобраться в параметрах.
- Автотесты. Команда bash tests/run_tests.sh проверяет весь проект целиком примерно за полминуты. Пригодится, если вы решите что-то поменять в коде.
- Эмулятор. Настоящая прошивка, собранная для настоящего микроконтроллера, исполняется на компьютере по тактам. Можно посмотреть, как турель реагирует на цель, ещё до покупки платы. Подробности — в главе 14 большого руководства.

## 5.5. Куда расти дальше

- Опциональные модули. Экран OLED прямо на турели, озвучка голосом через MP3-плеер, уведомления в Telegram с фотографией цели, 3D-печатные детали. Всё это включается одной строчкой в прошивке — глава 12 большого руководства.
- Свои сценарии. Турель отвечает на простые текстовые команды, поэтому её легко подчинить своему скрипту на любом языке. Сводка команд — в приложении Б этой книги.
- Другой «эффектор». Вместо лазера можно поставить, например, направленный вентилятор: получится безобидная и при этом действующая защита от комаров.
- Большое руководство. Когда освоитесь, откройте «ПВО_от_комаров_руководство.docx»: там те же темы, но глубже — протоколы, таблицы замен компонентов, диагностика, методики.

# Приложение А. Чеклист покупки (можно распечатать)

Отметьте галочками то, что уже купили. Первая колонка — для варианта A, с которого стоит начать.

✓ | Что | Для чего | Примерно
☐ | Arduino Nano или Uno (с распаянными ножками) | A, C | 500 ₽
☐ | USB-кабель С ЛИНИЯМИ ДАННЫХ | A | 150 ₽
☐ | Дальномер HC-SR04 | A | 100 ₽
☐ | Серво SG90 или MG90S | A | 200 ₽
☐ | Лазерный модуль KY-008 (≤5 мВт!) | A | 100 ₽
☐ | Буззер 5 В | A | 50 ₽
☐ | Макетная плата | A | 250 ₽
☐ | Набор проводов дюпон 3×40 | A | 250 ₽
☐ | Блок питания 5 В / 3 А + клеммник | A | 500 ₽
☐ | Конденсаторы 1000 мкФ ×2 | A | 40 ₽
☐ | ESP32 DevKit V1 | B | 550 ₽
☐ | Радар LD2450 или RD-03D | B | 800 ₽
☐ | Второе серво + кронштейн pan-tilt | B | 530 ₽
☐ | Транзисторы 2N2222 + резисторы 1 кОм | B, D | 70 ₽
☐ | Raspberry Pi + карта + блок питания | C | 7 900 ₽
☐ | Камера (для D — обязательно без ИК-фильтра) | C, D | 900 ₽
☐ | ИК-модуль подсветки 850 нм | D | 250 ₽
☐ | Термоклеевой пистолет | все | 450 ₽

# Приложение Б. Все команды турели

Команды набираются в мониторе порта Arduino IDE или во вкладке «Консоль» пульта и подтверждаются клавишей Enter.

Команда | Что делает | Где работает
? | показать состояние: режим, журнал, здоровье датчика | везде
G | показать все настройки | везде
S ИМЯ ЗНАЧЕНИЕ | изменить настройку, например S DETECT 80 | везде
W | сохранить настройки в память платы навсегда | везде
D | вернуть заводские настройки | везде
Z | обнулить журнал поражений | везде
C | поставить серво в центр на 8 секунд (для юстировки) | вариант B
L1 / L0 | включить / выключить лазер для проверки | вариант B
I1 / I0 | включить / выключить ИК-подсветку | вариант D
T | переинициализировать радар | вариант B
P90 | повернуть на 90° по команде извне | вариант A/C
R | вернуть самостоятельный режим | вариант A/C

Скорость порта: для Arduino (варианты A и C) — 9600 бод, для ESP32 (варианты B и D) — 115200. Если вместо текста идут иероглифы, вы просто выбрали не ту скорость в правом нижнем углу монитора.

# Приложение В. Словарь

Слово | Значение
Азимут | угол поворота влево-вправо. 90° — «прямо по курсу»
Гребёнка | рядок штырьков-контактов, который припаивается к плате
Дюпон | готовый провод с наконечником: «папа» — штырёк, «мама» — гнездо
Загрузчик (bootloader) | маленькая программа в плате, которая принимает вашу прошивку по USB
Захват | момент, когда турель поверила, что перед ней цель, и включила лазер
Кадр (радара) | одна порция данных от радара: координаты целей на текущий момент
Качалка | пластиковая крестовина или рычаг, которые надеваются на вал серво
Мёртвая зона | область, которую датчик не видит: слишком близко или слишком далеко
Патруль | режим, в котором турель осматривает сектор, пока целей нет
Пристрелка | совмещение того, куда смотрит камера, с тем, куда светит лазер
Сектор | диапазон углов, в котором турель работает
Сопровождение | режим, в котором турель ведёт захваченную цель
Телеметрия | поток коротких сообщений от турели о её состоянии — для пульта
Тилт (tilt) | наклон вверх-вниз. Пан (pan) — поворот влево-вправо
Юстировка | механическая настройка: выставить датчик и лазер так, чтобы они смотрели в одну точку

# Приложение Д. Что турель вам говорит

Турель постоянно пишет о себе в монитор порта. Вот расшифровка всех сообщений — держите под рукой, пока не запомните.

Сообщение | Что оно означает | Нужно ли что-то делать
=== ПВО-1К «Комар» … на боевом дежурстве === | турель включилась и готова | нет, это нормальный старт
Версия прошивки: 1.2 | какая программа залита в плату | пригодится, если что-то не совпадает с книгой
Самотест: датчик OK (эхо в 10/10 замеров…) | датчик проверен и отвечает | нет
Самотест: ДАТЧИК МОЛЧИТ | эхо не вернулось ни разу | проверьте питание датчика и провода TRIG/ECHO
Загрузка N7, журнал за всё время: 3 | турель включалась семь раз, засчитано три цели | если номер загрузки растёт сам — проблема с питанием
>>> ЦЕЛЬ ЗАХВАЧЕНА! Азимут 95 град | цель найдена, лазер включён | нет
*** Цель N4 поражена. Занесена в журнал *** | цель удерживалась KILLMS миллисекунд | нет, это ваша «победа»
<<< Цель потеряна — возвращаюсь к патрулированию | цель ушла из зоны | нет
<<< Лимит непрерывного сопровождения — пауза | сработал предохранитель TRACKMAX | нет; если мешает — увеличьте лимит
ТРЕВОГА: датчик молчит | эха нет уже полминуты | проверьте провода: скорее всего, что-то отошло
Датчик снова отвечает — тревога снята | связь восстановилась | нет
OK SAVED (параметры и журнал в EEPROM) | настройки сохранены в плату | нет
ERR имя или диапазон: … | команда S с неизвестным именем или значением вне допустимого | проверьте написание имени и границы в разделе 1.9
РАДАР МОЛЧИТ (вариант B) | радар не присылает кадры | проверьте TX/RX и питание 5 В радара
Зрение замолчало — веду по радару (вариант D) | компьютер перестал присылать поправки | нормально, если вы закрыли программу; иначе проверьте USB

# Приложение Е. Чеклист сборки (распечатать и отмечать)

Порядок, в котором стоит действовать, чтобы ничего не забыть. Отмечайте пункты по мере выполнения — это особенно помогает, если собираете не за один присест.

✓ | Шаг | Как понять, что получилось
☐ | Установлена Arduino IDE | программа запускается, видно окно с кодом
☐ | Плата определяется компьютером | в меню «Инструменты → Порт» есть порт
☐ | Залит пример Blink | светодиод на плате мигает раз в секунду
☐ | Питание макетки собрано | воткнутый в шины лазер светится
☐ | Подключено серво | при включении дёргается и встаёт ровно
☐ | Подключён дальномер | в мониторе идут осмысленные цифры дистанции
☐ | Подключены лазер и буззер | при старте лазер мигает дважды, буззер пищит
☐ | Датчик и лазер закреплены на качалке | смотрят в одну сторону, ничего не болтается
☐ | Залита прошивка турели | в мониторе появился баннер и самотест
☐ | Проверен захват цели | поднесли руку — лазер загорелся, в мониторе «ЦЕЛЬ ЗАХВАЧЕНА»
☐ | Настроен сектор | луч не выходит в дверь, окно и на уровень глаз
☐ | Подобраны пороги под комнату | нет ложных захватов за десять минут наблюдения
☐ | Настройки сохранены (W) | после выключения и включения значения на месте
☐ | Установлен пульт | программа подключается к турели и рисует радар
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

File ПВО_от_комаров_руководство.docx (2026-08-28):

ПВО ОТ КОМАРОВ

Семейство турелей «Комар»: ПВО-1К · ПВО-2К · ПВО-3К · ПВО-4К

Руководство по методологии, сборке, установке и настройке

Четыре варианта исполнения:

A — Arduino Uno/Nano + ультразвук HC-SR04

B — ESP32 + mmWave-радар LD2450 / RD-03D

C — Raspberry Pi + камера + Arduino

Версия 1.0 · 26 августа 2026

Проект pvo · скетчи pvo.ino, pvo_esp32.ino, скрипты pvo_vision.py, pvo_fusion.py

ВНИМАНИЕ, ЛАЗЕРНАЯ БЕЗОПАСНОСТЬ. В проекте используется только маломощный лазер-целеуказатель (класс 1/2, не более 5 мВт, обычный модуль KY-008). Лазеры, способные физически поражать насекомых, относятся к классам 3B/4 и мгновенно, необратимо повреждают зрение — в том числе отражённым лучом. Устанавливать такие лазеры в самонаводящуюся турель запрещено. Подробнее — раздел 2.

Оглавление

Если оглавление пустое — Word спросит про обновление полей при открытии (ответьте «Да») или нажмите Ctrl+A, затем F9.

# 1. О системе и методология

## 1.1. Идея и происхождение

Проект вдохновлён вирусным роликом «ПВО от комаров»: китайский инженер приспособил радар от электромобиля для обнаружения насекомых, закрепил рядом лазерную указку и вёл «журнал поражённых целей». Наша система воспроизводит этот сценарий на доступных компонентах: датчик обнаруживает движущуюся цель, поворотная турель наводит на неё лазер-целеуказатель, сопровождает, а «поражения» фиксируются в журнале через последовательный порт.

Система задумана как обучающий и развлекательный DIY-проект: это отличный полигон для освоения датчиков, сервоприводов, конечных автоматов, последовательных протоколов и компьютерного зрения.

## 1.2. Честная физика: кого система видит на самом деле

Прежде чем выбирать вариант, важно понимать пределы датчиков. Ультразвуковой дальномер HC-SR04 уверенно видит крупные цели (рука, человек, кот) на расстоянии до 1–2 м, но комар для него не существует: отражённого сигнала от объекта в несколько миллиметров попросту нет. Бытовые mmWave-радары LD2450/RD-03D спроектированы для отслеживания людей: они выдают готовые координаты целей, но их алгоритмы отфильтровывают всё, что меньше человека. Единственный реалистичный способ «увидеть» насекомое — камера с компьютерным зрением на контрастном фоне при хорошем освещении с дистанции 0,5–2 м.

Вывод: варианты A и B дают эффектную турель, отслеживающую крупные цели (и это ровно то, что показано в исходном видео), вариант C добавляет шанс реагировать на мелкие объекты вплоть до мух и комаров. Инженер из ролика использовал автомобильный радар с нестандартной обработкой сигнала — бытовыми модулями его результат не повторяется.
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

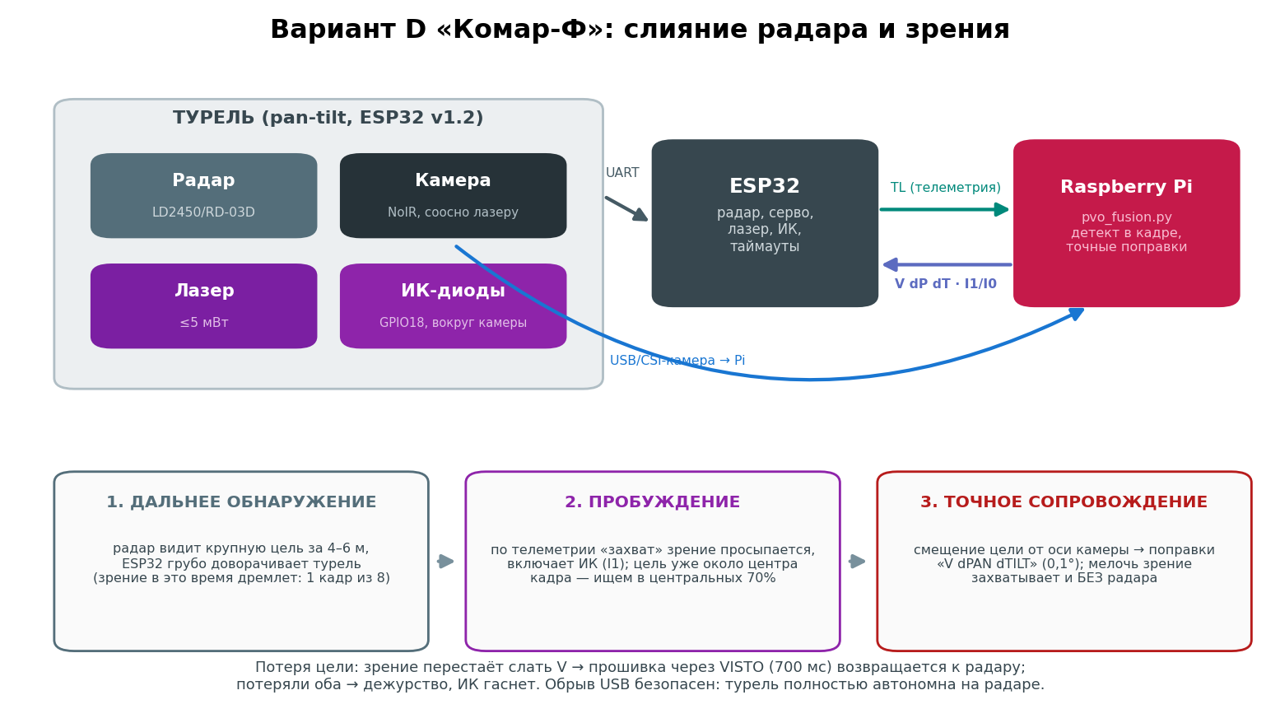
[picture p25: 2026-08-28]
fig/fig24_fusion.png

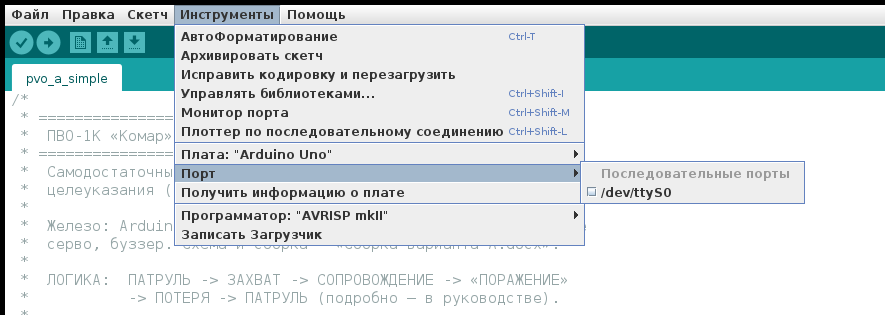
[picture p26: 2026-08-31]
fig/fig_b23_ide_port.png

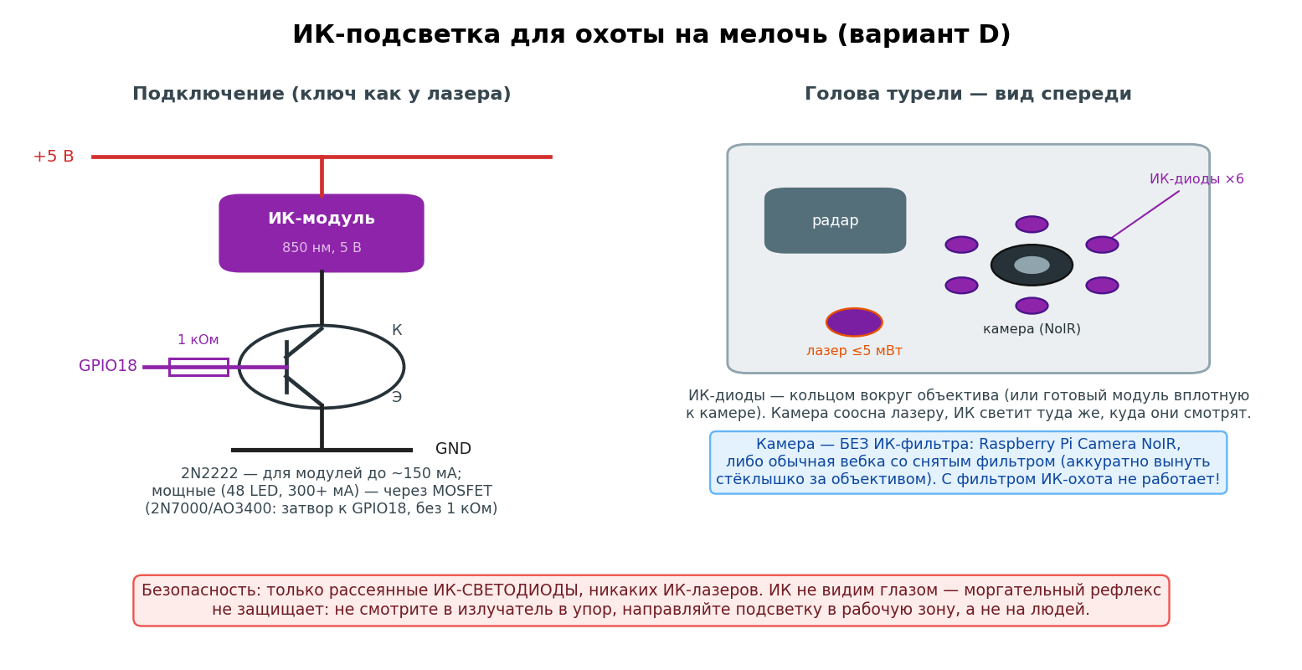
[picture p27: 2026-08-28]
fig/fig25_ir.png

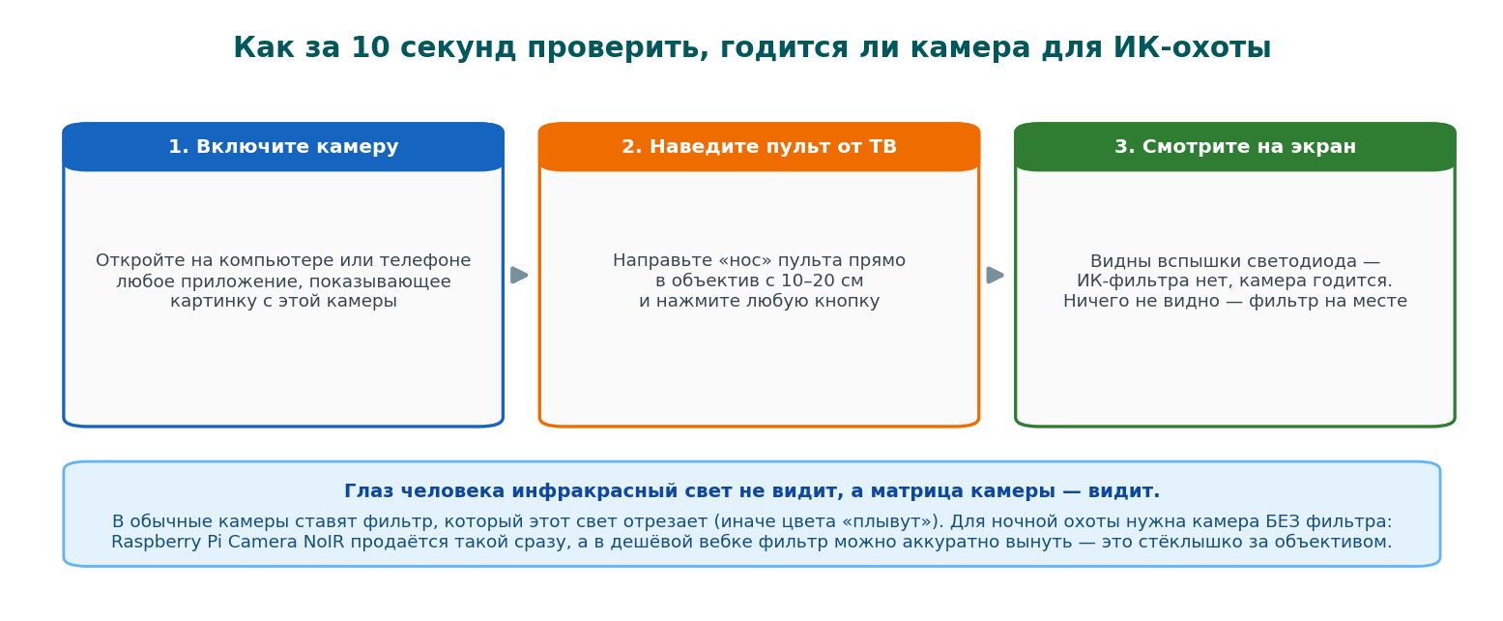
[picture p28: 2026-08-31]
fig/fig_b09_ircheck.png

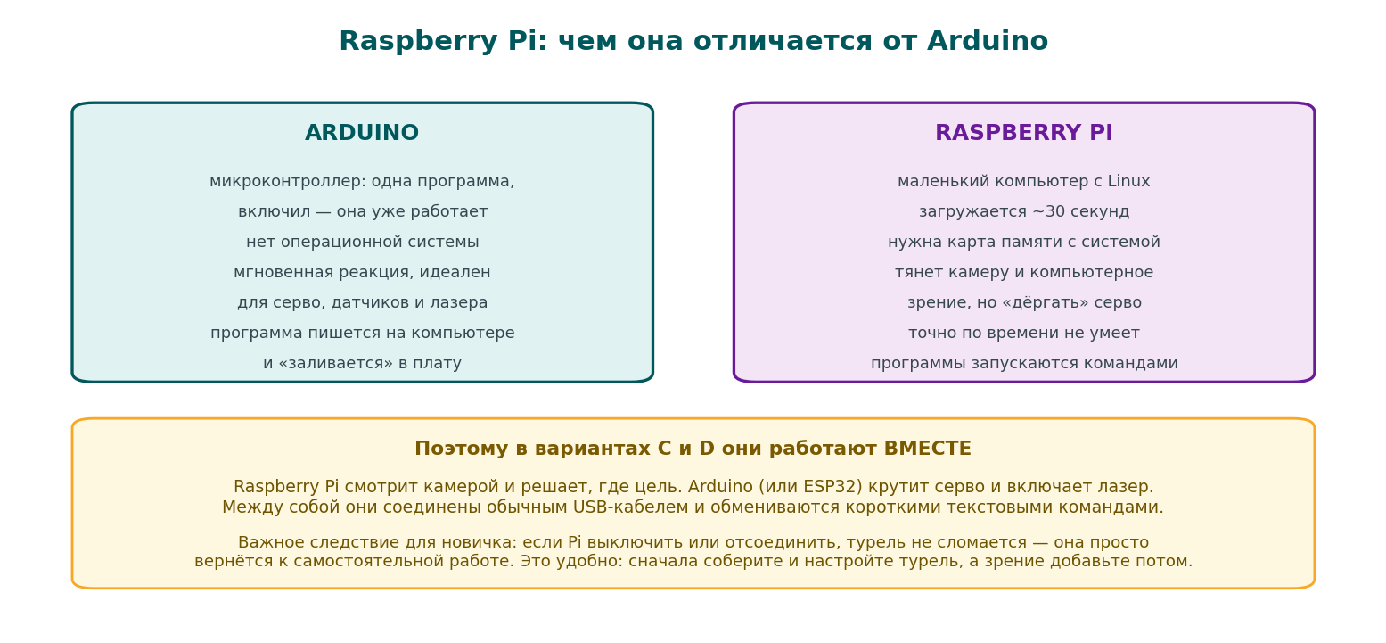
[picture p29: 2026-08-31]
fig/fig_b08_rpi.png

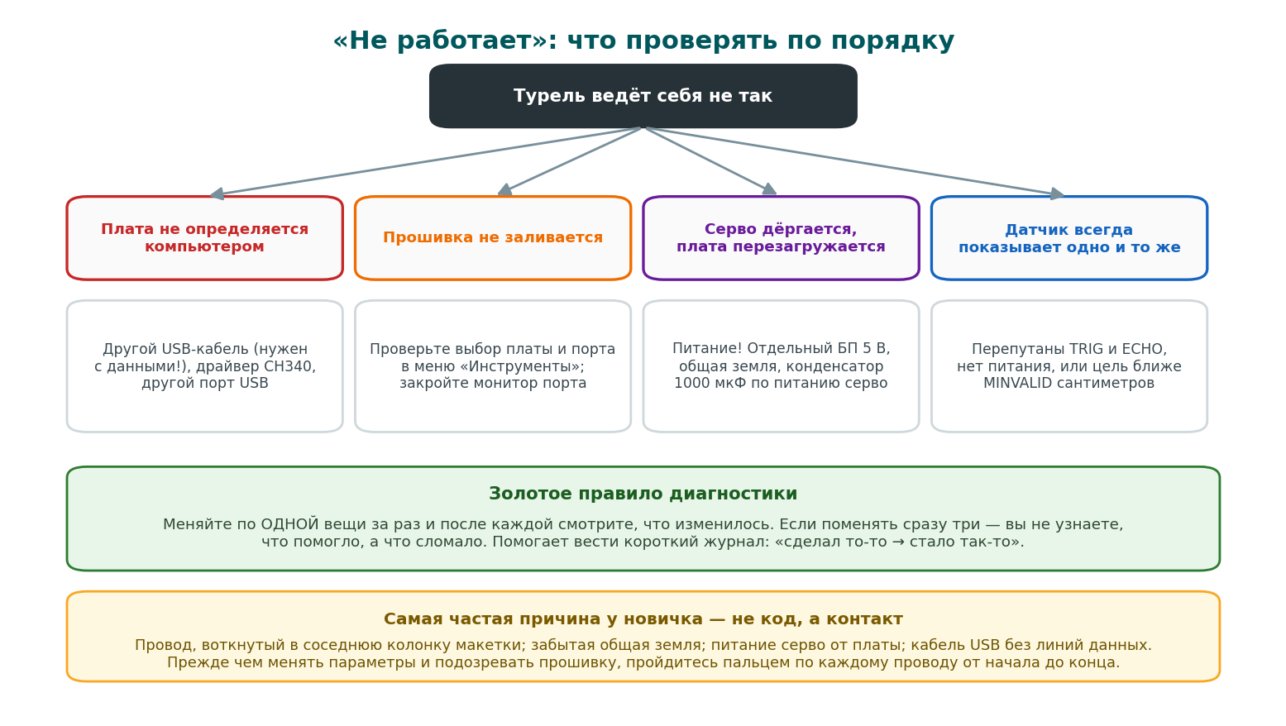
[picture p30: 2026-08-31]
fig/fig_b07_trouble.png

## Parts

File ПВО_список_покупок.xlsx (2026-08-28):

ПВО ОТ КОМАРОВ — полный список комплектующих (рекомендация)
Цены ориентировочные (Ozon/WB/AliExpress, авг 2026) — правьте синие ячейки под свои; жёлтая колонка «Куплено» — для отметок (любой символ). Итоги пересчитаются сами.
1. БАЗОВЫЙ НАБОР — нужен при любом варианте
№ | Компонент | Кол-во | Зачем нужен | Цена/шт, ₽ | Сумма, ₽ | Куплено | Примечание
1 | Лазерный модуль KY-008 (красный, ≤5 мВт) | 1 | целеуказатель турели | 100 ₽ | 100 ₽ |  | СТРОГО не мощнее 5 мВт — безопасность зрения
2 | Буззер активный 5 В | 1 | звуки захвата и «поражения» | 50 ₽ | 50 ₽ |  | пьезо тоже подойдёт
3 | Провода Dupont, набор 3×40 шт (п-п, п-м, м-м) | 1 | вся коммутация без пайки | 250 ₽ | 250 ₽ |  | 20 см удобнее всего
4 | Макетная плата 830 точек | 1 | сборка схемы без пайки | 250 ₽ | 250 ₽ |  | или 400 точек за ~150 ₽
5 | Блок питания 5 В / 3 А (штекер 5,5×2,1) | 1 | питание серво и радара | 450 ₽ | 450 ₽ |  | 3 А закрывает варианты A и B с запасом
6 | Переходник DC 5,5×2,1 → клеммник | 1 | подключить БП к макетке | 60 ₽ | 60 ₽
7 | Конденсатор 1000 мкФ / 16 В | 2 | сглаживание бросков тока серво | 20 ₽ | 40 ₽ |  | ставится по питанию серво
8 | Основание (фанера/пластик) + винты М2/М3, набор | 1 | неподвижная база турели | 200 ₽ | 200 ₽ |  | подойдёт и обрезок доски
Итого по разделу: |  |  |  |  | 1400 ₽
2. ЯДРО «КАК В ВИДЕО» — вариант B (рекомендую)
№ | Компонент | Кол-во | Зачем нужен | Цена/шт, ₽ | Сумма, ₽ | Куплено | Примечание
9 | ESP32 DevKit V1 (WROOM-32, 30 pin) | 1 | мозг: приём радара, наведение, Wi-Fi на будущее | 550 ₽ | 550 ₽ |  | берите с распаянными гребёнками; чип USB — CP2102 или CH340
10 | Радар HLK-LD2450 | 1 | координаты до 3 движущихся целей, 256000 бод | 800 ₽ | 800 ₽ |  | альтернатива: Ai-Thinker RD-03D ~550 ₽ (протокол совместим, поддержан прошивкой)
11 | Серво MG90S (металлический редуктор) | 2 | оси pan и tilt | 230 ₽ | 460 ₽ |  | SG90 дешевле, но люфтит и живёт меньше
12 | Pan-tilt кронштейн под SG90/MG90S | 1 | механика двух осей | 300 ₽ | 300 ₽ |  | готовый комплект с винтами
13 | Транзистор 2N2222 (или BC337) | 2 | ключ лазера от GPIO 3,3 В | 10 ₽ | 20 ₽ |  | второй — про запас
14 | Резисторы 1 кОм (набор) | 1 | в базу транзистора | 60 ₽ | 60 ₽ |  | любой набор выводных резисторов
15 | Кабель USB для прошивки (с линиями данных!) | 1 | прошивка и монитор порта | 150 ₽ | 150 ₽ |  | смотрите разъём своей платы: micro-USB или USB-C; «зарядные» кабели не годятся
Итого по разделу: |  |  |  |  | 2340 ₽
3. БЮДЖЕТНЫЙ СТАРТ — вариант A (если начать проще)
№ | Компонент | Кол-во | Зачем нужен | Цена/шт, ₽ | Сумма, ₽ | Куплено | Примечание
16 | Arduino Nano (CH340, распаянный) | 1 | мозг сканирующей турели | 400 ₽ | 400 ₽ |  | или Uno R3 клон ~600 ₽; понадобится драйвер CH340
17 | Ультразвуковой дальномер HC-SR04 | 1 | «радар»: дистанция до цели | 100 ₽ | 100 ₽
18 | Серво SG90 | 1 | ось азимута | 160 ₽ | 160 ₽ |  | можно взять MG90S из раздела 2 — он лучше
19 | Кабель mini-USB (Nano) или USB-B (Uno) | 1 | прошивка | 130 ₽ | 130 ₽ |  | тоже с линиями данных
Итого по разделу: |  |  |  |  | 790 ₽
4. АПГРЕЙД «ЗРЕНИЕ» — вариант C (можно докупить потом)
№ | Компонент | Кол-во | Зачем нужен | Цена/шт, ₽ | Сумма, ₽ | Куплено | Примечание
20 | Raspberry Pi 4 (4 ГБ) | 1 | компьютерное зрение (OpenCV) | 6500 ₽ | 6500 ₽ |  | или Pi 5; бюджетно — Zero 2 W ~3000 ₽ (ниже FPS)
21 | Камера USB 1080p (или Camera Module 3) | 1 | «глаза» системы | 900 ₽ | 900 ₽ |  | CSI-модуль ~4000 ₽ — лучше в темноте, нужен шлейф под вашу Pi
22 | microSD 32 ГБ (класс A1/U3) | 1 | система Raspberry Pi OS | 500 ₽ | 500 ₽ |  | качественная карта — залог стабильности
23 | БП USB-C 5 В / 3 А | 1 | питание Raspberry Pi | 900 ₽ | 900 ₽ |  | фирменный или качественный — Pi чувствительна к просадкам
24 | Корпус с охлаждением / радиаторы | 1 | тепловой режим Pi | 500 ₽ | 500 ₽ |  | необязательно, но желательно
Итого по разделу: |  |  |  |  | 9300 ₽
5. ИК-ОХОТА — вариант D «Комар-Ф» (слияние B + C, глава 13)
№ | Компонент | Кол-во | Зачем нужен | Цена/шт, ₽ | Сумма, ₽ | Куплено | Примечание
25 | ИК-модуль подсветки 850 нм (плата от камер наблюдения) | 1 | невидимая подсветка мелочи: мошки, комары | 250 ₽ | 250 ₽ |  | или 3–6 ИК-диодов 850 нм кольцом вокруг объектива; 940 нм камера видит заметно хуже
26 | Камера БЕЗ ИК-фильтра | 1 | обязательна для ИК-охоты (обычные камеры ИК не видят) | 0 ₽ | 0 ₽ |  | 0 ₽ — снять фильтр с вебки из раздела 4; или готовая Raspberry Pi Camera NoIR (CSI) ~1500–2500 ₽
27 | MOSFET 2N7000 или AO3400 | 1 | ключ ИК-платы при токе больше ~150 мА | 20 ₽ | 20 ₽ |  | мелкой подсветке (до ~150 мА) хватит 2N2222 из раздела 2
Итого по разделу: |  |  |  |  | 270 ₽
6. ОПЦИОНАЛЬНЫЕ МОДУЛИ — украшения по вкусу
№ | Компонент | Кол-во | Зачем нужен | Цена/шт, ₽ | Сумма, ₽ | Куплено | Примечание
28 | OLED-экран SSD1306 0,96" I2C | 1 | «экран боевого поста» на турели (вариант B) | 250 ₽ | 250 ₽ |  | адрес 0x3C; библиотека Adafruit SSD1306
29 | DFPlayer Mini | 1 | озвучка событий голосом/звуками | 150 ₽ | 150 ₽ |  | библиотека не нужна — протокол в прошивке
30 | Динамик 3 Вт 4–8 Ом | 1 | к DFPlayer | 120 ₽ | 120 ₽ |  | или маленький «квадратик» 2 Вт
31 | microSD 1–8 ГБ | 1 | дорожки /mp3/0001..0005.mp3 | 250 ₽ | 250 ₽ |  | подойдёт любая старая
Итого по разделу: |  |  |  |  | 770 ₽
7. ИНСТРУМЕНТЫ — если ещё нет
№ | Компонент | Кол-во | Зачем нужен | Цена/шт, ₽ | Сумма, ₽ | Куплено | Примечание
32 | Термоклеевой пистолет + стержни | 1 | крепёж датчика и лазера на качалке | 450 ₽ | 450 ₽
33 | Мультиметр (DT-830 или лучше) | 1 | проверка питания и прозвонка | 500 ₽ | 500 ₽
34 | Паяльник 60 Вт + припой + флюс | 1 | гребёнки радара/плат | 800 ₽ | 800 ₽ |  | радары часто приходят без распаянных гребёнок — паяльник почти наверняка понадобится
35 | Набор малых отвёрток (крест) | 1 | винты серво и кронштейна | 250 ₽ | 250 ₽
Итого по разделу: |  |  |  |  | 2000 ₽
СВОДКА: сколько стоит каждая конфигурация
Рекомендую: базовый набор + ядро B (радарная турель «как в видео») |  |  |  |  | 3740 ₽
Бюджетный старт: базовый набор + вариант A (сканирующая турель) |  |  |  |  | 2190 ₽
Обе турели: базовый + A + B (коду ничего докупать не надо) |  |  |  |  | 4530 ₽
Полная программа: базовый + A + B + зрение C |  |  |  |  | 13830 ₽
Слияние D «Комар-Ф»: базовый + B + зрение C + ИК-охота |  |  |  |  | 13310 ₽
Опциональные модули (по вкусу) |  |  |  |  | 770 ₽
Инструменты (если совсем с нуля) |  |  |  |  | 2000 ₽
Синие значения (кол-во и цена) — правьте под фактические цены магазина. Источник цен: ориентировочные рыночные, авг 2026 (пользовательская оценка проекта). Лазер — только ≤5 мВт, см. раздел 2 руководства.

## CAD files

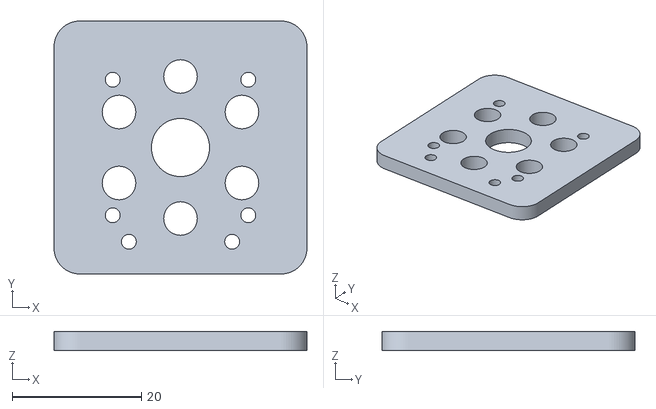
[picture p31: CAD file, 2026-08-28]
3d/stl/cam_face.stl
39.2 x 39.2 x 3.00

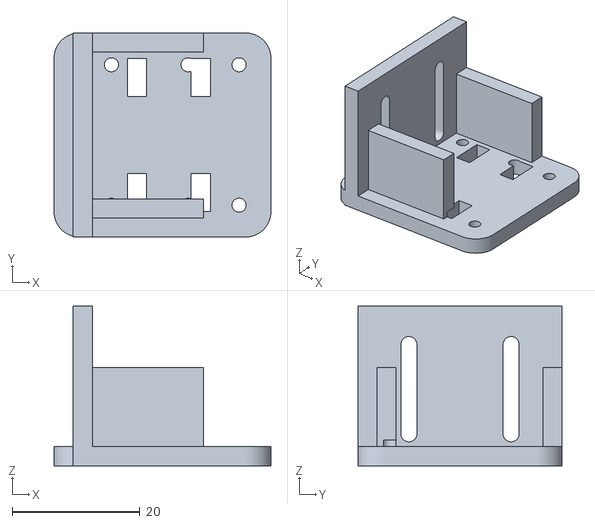
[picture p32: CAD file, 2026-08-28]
3d/stl/cam_cradle.stl
34.0 x 32.0 x 25.0

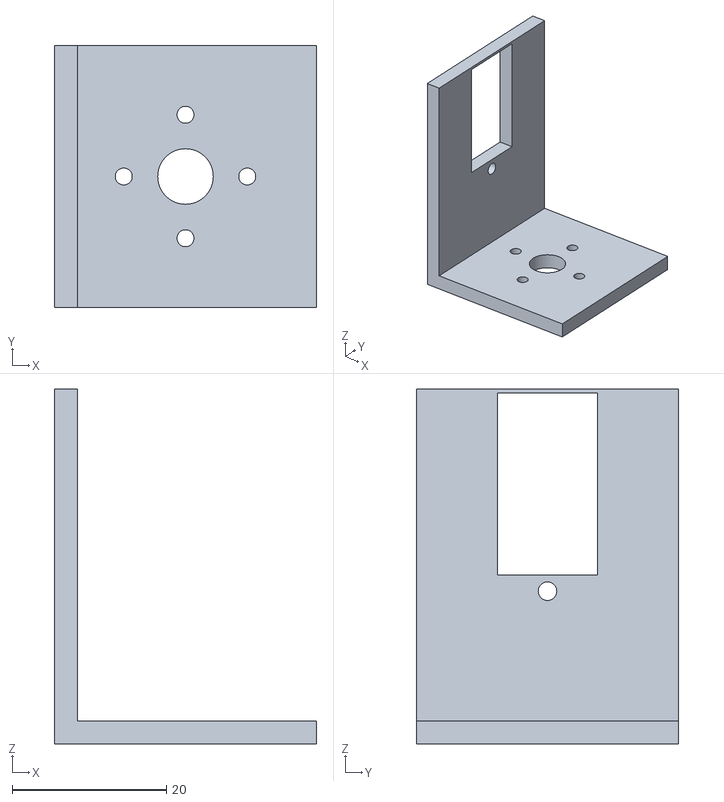
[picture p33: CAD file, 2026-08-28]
3d/stl/pan_tilt_bracket.stl
34.0 x 34.0 x 46.0

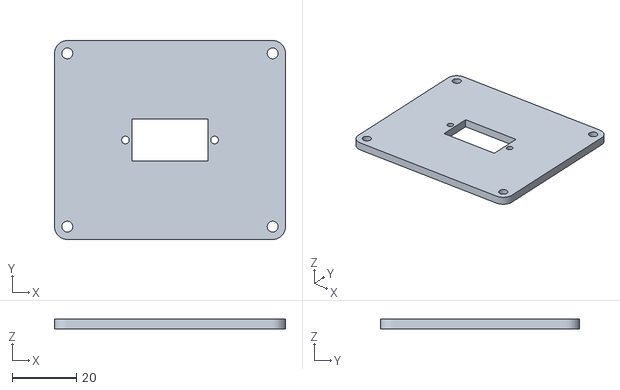
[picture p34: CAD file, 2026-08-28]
3d/stl/pan_tilt_base.stl
72.0 x 62.0 x 3.00

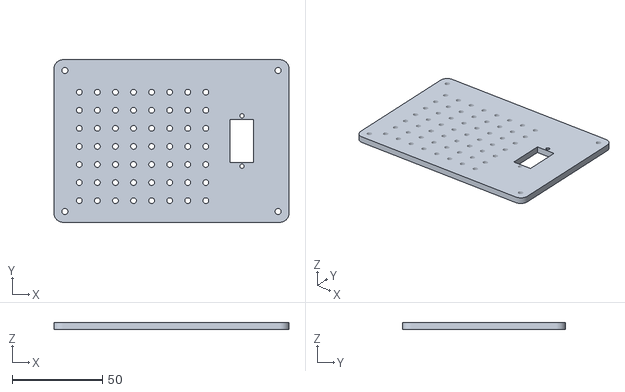
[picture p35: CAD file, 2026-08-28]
3d/stl/base_a.stl
130.0 x 90.0 x 4.00

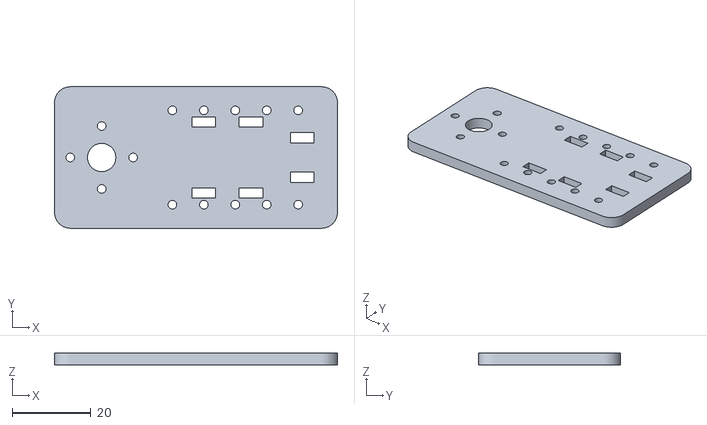
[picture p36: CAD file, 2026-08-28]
3d/stl/pan_tilt_plate.stl
72.0 x 36.0 x 3.00

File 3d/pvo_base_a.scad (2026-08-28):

// ============================================================
//  ПВО от комаров — печатное основание варианта A (Uno + HC-SR04)
//  Плита: окно под серво + монтажное поле для платы и макетки.
//  OpenSCAD, размеры в мм. Печать: PLA, слой 0.2, без поддержек.
//
//  Серво ставится в окно ушами вниз и прикручивается саморезами;
//  Arduino и макетка крепятся стяжками через поле отверстий
//  (шаг 10 мм) или на двусторонний скотч.
// ============================================================

plate_l = 130;
plate_w = 90;
wall    = 4;

// серво SG90/MG90S (замерьте свои!)
servo_l    = 23.2;
servo_w    = 12.6;
ear_hole_d = 2.4;
ear_hole_s = 27.8;
tol        = 0.4;

$fn = 48;

module servo_cut() {
  square([servo_l + tol, servo_w + tol], center = true);
  for (dx = [-ear_hole_s / 2, ear_hole_s / 2])
    translate([dx, 0]) circle(d = ear_hole_d);
}

difference() {
  linear_extrude(wall) hull()
    for (x = [-plate_l / 2 + 5, plate_l / 2 - 5],
         y = [-plate_w / 2 + 5, plate_w / 2 - 5])
      translate([x, y]) circle(r = 5);

  translate([0, 0, -1]) linear_extrude(wall + 2) {
    // окно серво — ближе к «носу» плиты
    translate([plate_l / 2 - 26, 0]) rotate(90) servo_cut();

    // поле отверстий 2×3 мм с шагом 10 мм под стяжки/винты
    for (x = [-plate_l / 2 + 14 : 10 : plate_l / 2 - 40],
         y = [-plate_w / 2 + 12 : 10 : plate_w / 2 - 12])
      translate([x, y]) circle(d = 3.2);

    // угловые крепления к столу/фанере
    for (x = [-plate_l / 2 + 6, plate_l / 2 - 6],
         y = [-plate_w / 2 + 6, plate_w / 2 - 6])
      translate([x, y]) circle(d = 3.4);
  }
}

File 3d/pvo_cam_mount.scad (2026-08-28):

// ============================================================
//  ПВО от комаров — держатель камеры с кольцом ИК-диодов
//  (вариант D «Комар-Ф»). OpenSCAD, размеры в мм.
//
//  Зачем: в варианте D камера — это ПРИЦЕЛ. Её ось должна быть
//  параллельна лучу лазера и жёстко зафиксирована: любой сдвиг
//  после пристрелки уводит луч. Термоклей этого не держит.
//
//  Что печатается:
//    face  — лицевая панель: окно под объектив, кольцо гнёзд
//            под ИК-диоды 5 мм, лапки под стяжки;
//    cradle— люлька: сажает панель на площадку plate варианта B
//            рядом с лазером, соосно ему;
//    both  — обе детали рядом (по умолчанию).
//
//  ПЕРЕД ПЕЧАТЬЮ замерьте свою камеру и поправьте cam_* ниже.
//  Значения по умолчанию — Raspberry Pi Camera v2/NoIR (25×24 мм).
//
//  Печать: PLA/PETG, слой 0.2, 3 периметра, 25%, без поддержек.
//  Сборка и пристрелка — руководство, глава 13 и «Сборка вариант D».
// ============================================================

// ---- что рендерить: "both" | "face" | "cradle" -------------
part = "both";

// ---- камера ------------------------------------------------
cam_w      = 25.0;   // ширина платы камеры
cam_h      = 24.0;   // высота платы камеры
cam_hole_s = 21.0;   // расстояние между крепёжными отверстиями (квадрат)
cam_hole_d = 2.3;    // отверстия под винты М2
lens_d     = 9.0;    // окно под объектив (с запасом)

// ---- ИК-подсветка ------------------------------------------
led_d      = 5.2;    // диоды 5 мм (+ зазор)
led_n      = 6;      // сколько диодов в кольце
led_ring_r = 11.0;   // радиус кольца от оси объектива
                     // (готовый модуль подсветки — см. ir_module_slot)
ir_module  = false;  // true: вместо кольца — окно под готовую ИК-плату
ir_mod_w   = 38;     // её размеры
ir_mod_h   = 38;

// ---- крепёж панели к стойке --------------------------------
mnt_s      = 16;     // расстояние между винтами М2 (панель <-> стойка)
mnt_d      = 2.3;    // отверстия под М2
slot_h     = 14;     // высота паза в стойке: настройка высоты объектива
                     // ПОСЛЕ печати — двигайте панель, пока ось объектива
                     // не совпадёт с осью лазера, потом затяните

// ---- посадка на площадку -----------------------------------
plate_thick = 3;     // толщина площадки plate из pvo_pan_tilt.scad
laser_axis_z = 14;   // высота оси лазера над площадкой: подгоните
                     // так, чтобы объектив встал на ту же высоту
wall       = 3;
tol        = 0.4;
$fn = 64;

// ============================================================
module ziptie_pair(len = 6, gap = 14) {     // прорези под стяжку
  for (dy = [-gap / 2, gap / 2])
    translate([0, dy]) square([3, len], center = true);
}

// ---- лицевая панель ----------------------------------------
module face() {
  fw = max(cam_w, ir_module ? ir_mod_w : led_ring_r * 2 + led_d + 6) + 2 * wall;
  fh = max(cam_h, ir_module ? ir_mod_h : led_ring_r * 2 + led_d + 6) + 2 * wall;
  difference() {
    linear_extrude(wall) hull()
      for (x = [-fw / 2 + 4, fw / 2 - 4], y = [-fh / 2 + 4, fh / 2 - 4])
        translate([x, y]) circle(r = 4);

    translate([0, 0, -1]) linear_extrude(wall + 2) {
      circle(d = lens_d);                            // окно объектива
      for (dx = [-cam_hole_s / 2, cam_hole_s / 2],   // винты камеры М2
           dy = [-cam_hole_s / 2, cam_hole_s / 2])
        translate([dx, dy]) circle(d = cam_hole_d);
      for (dx = [-mnt_s / 2, mnt_s / 2])              // винты к стойке
        translate([dx, -fh / 2 + wall + 2]) circle(d = mnt_d);
      if (ir_module)                                  // окно под готовую плату
        square([ir_mod_w + tol, ir_mod_h + tol], center = true);
      else
        for (i = [0 : led_n - 1])                     // кольцо гнёзд под диоды
          rotate(360 / led_n * i + 30)
            translate([led_ring_r, 0]) circle(d = led_d);
    }
  }
}

// ---- люлька: панель -> площадка турели ---------------------
module cradle() {
  base_l = 34;                       // вдоль площадки
  base_w = max(cam_w, 26) + 2 * wall;
  h = max(laser_axis_z, slot_h + 8);
  difference() {
    union() {
      linear_extrude(wall)           // подошва
        hull() for (x = [-base_l / 2 + 4, base_l / 2 - 4],
                    y = [-base_w / 2 + 4, base_w / 2 - 4])
          translate([x, y]) circle(r = 4);
      translate([-base_l / 2 + wall, -base_w / 2, 0])   // задняя стойка
        cube([wall, base_w, h + wall]);
      for (dy = [-1, 1])                                // рёбра жёсткости
        translate([-base_l / 2 + wall, dy * (base_w / 2 - wall), 0])
          rotate([0, 0, 0]) cube([base_l * 0.6, wall, h * 0.7]);
    }
    translate([0, 0, -1]) linear_extrude(wall + 2) {
      translate([6, 0]) ziptie_pair(gap = 18);          // стяжками к площадке
      translate([-4, 0]) ziptie_pair(gap = 18);
      for (x = [-8, 4, 12], y = [-base_w / 2 + 5, base_w / 2 - 5])
        translate([x, y]) circle(d = 2.2);              // запасные 2 мм
    }
    // ВЕРТИКАЛЬНЫЕ ПАЗЫ в стойке: высота панели регулируется после печати,
    // чтобы ось объектива встала точно на ось лазера (см. главу 13).
    for (dy = [-mnt_s / 2, mnt_s / 2])
      translate([-base_l / 2 + wall * 1.5, dy, wall + slot_h / 2 + 2])
        hull() for (dz = [-slot_h / 2, slot_h / 2])
          translate([0, 0, dz]) rotate([0, 90, 0])
            cylinder(d = mnt_d + 0.2, h = wall + 4, center = true);
  }
}

// ============================================================
if (part == "face")        face();
else if (part == "cradle") cradle();
else {
  face();
  translate([0, 55, 0]) cradle();
}

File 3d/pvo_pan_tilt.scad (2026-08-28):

// ============================================================
//  ПВО от комаров — печатный pan-tilt кронштейн (вариант B)
//  Под серво SG90 / MG90S. OpenSCAD, все размеры в мм.
//
//  ПЕРЕД ПЕЧАТЬЮ: замерьте штангенциркулем СВОИ серво и поправьте
//  параметры ниже — у клонов размеры гуляют на ±0,5 мм.
//
//  Печать: PLA/PETG, слой 0.2, 3 периметра, заполнение 25%,
//  поддержки не нужны (все детали печатаются плашмя).
//
//  Сборка: base на основание → серво PAN в окно base →
//  bracket на качалку PAN → серво TILT в окно bracket →
//  plate на качалку TILT → радар и лазер стяжками в прорези.
// ============================================================

// ---- что рендерить: "all" | "base" | "bracket" | "plate" ----
part = "all";

// ---- размеры серво (SG90/MG90S типовые) --------------------
servo_l    = 23.2;   // длина корпуса
servo_w    = 12.6;   // ширина корпуса
ear_span   = 32.6;   // размах ушей
ear_hole_d = 2.4;    // отверстия ушей (саморез 2 мм)
ear_hole_s = 27.8;   // расстояние между отверстиями
tol        = 0.4;    // зазор посадки

// ---- прочее ------------------------------------------------
wall       = 3;      // толщина стенок/плит
horn_d     = 7.2;    // отверстие под втулку качалки
horn_r     = 8;      // радиус винтов крестовины качалки
horn_hole  = 2.2;    // отверстия под винты качалки
$fn = 48;

// ============================================================
module servo_window() {                     // сквозное окно под корпус
  square([servo_l + tol, servo_w + tol], center = true);
}
module ear_holes() {                        // отверстия ушей
  for (dx = [-ear_hole_s / 2, ear_hole_s / 2])
    translate([dx, 0]) circle(d = ear_hole_d);
}
module horn_mount() {                       // под круглую крестовину качалки
  circle(d = horn_d);
  for (a = [0, 90, 180, 270])
    rotate(a) translate([horn_r, 0]) circle(d = horn_hole);
}
module ziptie_pair(len = 6, gap = 14) {     // пара прорезей под стяжку
  for (dy = [-gap / 2, gap / 2])
    translate([0, dy]) square([len, 2.6], center = true);
}

// ============================================================
//  1) BASE — плита с окном серво PAN
// ============================================================
module base() {
  difference() {
    linear_extrude(wall) hull()
      for (x = [-32, 32], y = [-27, 27])
        translate([x, y]) circle(r = 4);
    translate([0, 0, -1]) linear_extrude(wall + 2) {
      servo_window();
      ear_holes();
      for (x = [-32, 32], y = [-27, 27])      // крепёж к основанию
        translate([x, y]) circle(d = 3.4);
    }
  }
}

// ============================================================
//  2) BRACKET — Г-скоба: низ на качалку PAN, стенка с серво TILT
// ============================================================
br_w = 34;            // ширина скобы
br_base_l = 34;       // длина подошвы
br_h = 46;            // высота стенки

module bracket() {
  // подошва с крестовиной качалки PAN
  difference() {
    linear_extrude(wall) translate([br_base_l / 2, 0])
      square([br_base_l, br_w], center = true);
    translate([br_base_l / 2, 0, -1]) linear_extrude(wall + 2) horn_mount();
  }
  // стенка с окном серво TILT (осью качалки вперёд)
  difference() {
    translate([0, -br_w / 2, 0]) cube([wall, br_w, br_h]);
    translate([-1, 0, br_h - 6 - servo_w / 2])
      rotate([0, 90, 0]) linear_extrude(wall + 2) {
        servo_window();
        ear_holes();
      }
  }
  // косынка жёсткости
  translate([0, -br_w / 2, 0])
    rotate([90, 0, 90]) linear_extrude(wall)
      polygon([[0, 0], [br_w, 0], [br_w / 2, 12]]);
}

// ============================================================
//  3) PLATE — площадка радара и лазера на качалку TILT
// ============================================================
pl_l = 72;
pl_w = 36;

module plate() {
  difference() {
    linear_extrude(wall) hull()
      for (x = [-pl_l / 2 + 4, pl_l / 2 - 4], y = [-pl_w / 2 + 4, pl_w / 2 - 4])
        translate([x, y]) circle(r = 4);
    translate([0, 0, -1]) linear_extrude(wall + 2) {
      translate([-pl_l / 2 + 12, 0]) horn_mount();      // на качалку TILT
      translate([2, 0])  ziptie_pair(gap = 18);         // радар (2 стяжки)
      translate([14, 0]) ziptie_pair(gap = 18);
      translate([27, 0]) ziptie_pair(gap = 10);         // лазер
      for (x = [-6 : 8 : 30], y = [-12, 12])            // запасные 2 мм
        translate([x, y]) circle(d = 2.2);
    }
  }
}

// ============================================================
if (part == "base")         base();
else if (part == "bracket") bracket();
else if (part == "plate")   plate();
else {                                    // все детали рядом
  base();
  translate([0, 75, 0])  bracket();
  translate([0, 145, 0]) plate();
}

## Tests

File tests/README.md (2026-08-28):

# Тесты проекта — без железа

Прошивки проверяются на обычном компьютере: заглушки Arduino API (`stub_uno/`, `stub_esp32/`) компилируют скетчи через g++ и прогоняют сценарии «патруль → захват → поражение → потеря → отказ датчика/радара → восстановление → протокол настройки».

## Запуск всего

```bash
bash tests/run_tests.sh
```

Нужны `g++` и `python3` с пакетами: `pip install opencv-python-headless numpy`.

## Что проверяется

| Тест | Покрытие |
|---|---|
| `stub_uno/main.cpp` + `pvo.ino` | автомат режимов, SLAVE, тревога датчика, EEPROM, G/S/W/D/M |
| `stub_uno/main_a.cpp` + `pvo_a_simple.ino` | упрощённый вариант A целиком |
| `stub_esp32/main32.cpp` + `pvo_esp32.ino` | декодер радара (контрольные байты из протокола), захват по координатам, тревога/восстановление радара, битые кадры, консоль, G/S/W/D/M |
| `test_vision.py` | детектор на синтетике, геометрия наведения, валидация конфига, фотофиксация |
| `test_gui_logic.py` | разбор протокола, сверка имён параметров GUI ↔ прошивки, CSV журнала, демо-турель |
| `test_fusion.py` | вариант D: геометрия поправок V, детектор ярких точек (ИК), дрёма/пробуждение, захват зрением без радара, ограничения и rate-limit |
| `avr/run_scenarios.sh` | **эмулятор ATmega328P**: настоящая прошивка (avr-gcc + ядро Arduino) исполняется по тактам в avr8js — размер во flash/RAM, реальные тайминги, настоящая EEPROM между перезагрузками |

## Эмулятор ATmega328P — прошивка «как на плате»

Тесты на заглушках проверяют логику, но собирают скетч под x86 с ненастоящим Arduino API. Эмулятор идёт дальше: `avr-gcc` собирает прошивку под настоящий ATmega328P (там `int` 16-битный, `F()` живёт в PROGMEM, EEPROM — 1 КБ), а `avr8js` (тот же движок, что у Wokwi) исполняет её по тактам вместе с таймерами, UART и EEPROM. Стенд имитирует HC-SR04 (эхо по TRIG), меряет ШИМ серво и следит за пином лазера.

Установка (один раз):

```bash
sudo apt install gcc-avr avr-libc arduino-core-avr
(cd tests/avr/js && npm install)
```

Запуск всех сценариев (~15 секунд):

```bash
bash tests/avr/run_scenarios.sh
```

Свой прогон:

```bash
bash tests/avr/build_avr.sh pvo.ino                 # сборка + размер прошивки
node tests/avr/js/run_avr.mjs /tmp/avrbuild/firmware.hex \
     --seconds 14 --target-at 40,7 --target-gone 11 \
     --send "S DETECT 80@3" --expect "ЦЕЛЬ ЗАХВАЧЕНА"
```

Текущие размеры (ATmega328P, 32 КБ flash / 2 КБ RAM):

| Прошивка | Flash | RAM |
|---|---|---|
| `pvo_a_simple.ino` | 9 354 Б (28,5%) | 363 Б (17,7%) |
| `pvo.ino` | 14 490 Б (44,2%) | 547 Б (26,7%) |
| `pvo.ino` + DFPlayer | 15 798 Б (48,2%) | 596 Б (29,1%) |

Что эмулятор **не** проверит: механику (люфт, вес, перегрев серво), физику ультразвука и радара, лазер и ИК-подсветку (для него это просто пины), пристрелку варианта D. И ESP32 он не эмулирует — для варианта B удобен браузерный Wokwi.

Оговорка про Servo: в Debian-пакете `arduino-core-avr` библиотеки Servo нет, поэтому в `tests/avr/Servo/` лежит совместимая реализация на Timer1 (50 Гц, 544–2400 мкс) — только для стенда. На плате используется штатная библиотека из Arduino IDE.

## Симулятор турели для GUI (Linux/macOS)

`sim_turret.py` изображает прошивку на виртуальном порту — можно гонять пульт без платы (в самом пульте для этого проще выбрать порт «ДЕМО»):

```bash
socat -d0 pty,raw,echo=0,link=/tmp/ptyA pty,raw,echo=0,link=/tmp/ptyB &
python3 tests/sim_turret.py /tmp/ptyA uno     # или esp32
python3 pvo_gui.py --port /tmp/ptyB --connect
```

## CI на GitHub (по желанию)

Готовый workflow лежит рядом: `github-workflow-tests.yml`. Если выложите проект на GitHub — скопируйте его в `.github/workflows/tests.yml`, и весь стенд будет прогоняться на каждый push.

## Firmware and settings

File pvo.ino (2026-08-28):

/*
 * ============================================================
 *  ПВО-1К «Комар» — полная прошивка Uno/Nano (варианты A и C)
 * ============================================================
 *  Uno/Nano + HC-SR04 + серво + лазер <=5 мВт + буззер.
 *  Автономная логика варианта A + режим SLAVE (внешнее
 *  целеуказание от Raspberry Pi) + протокол удалённой настройки
 *  для GUI-приложения pvo_gui.py (Windows/Mac).
 *  Минимальная учебная версия без всего этого — pvo_a_simple.ino.
 *
 *  РЕЖИМЫ:  ПАТРУЛЬ ⇄ СОПРОВОЖДЕНИЕ (автономно), SLAVE (внешн.)
 *
 *  ПРОТОКОЛ (Serial 9600, строки с \n; используется и GUI):
 *   P<угол>       навести на угол, лазер ВКЛ, режим SLAVE
 *   R             сброс SLAVE -> автономный патруль
 *   ?             статус одной строкой
 *   G             выдать все параметры: PARAM ИМЯ=ЗНАЧ … PARAM END
 *   S ИМЯ ЗНАЧ    установить параметр (проверка диапазона)
 *   W             сохранить параметры и журнал в EEPROM
 *   D             вернуть параметры по умолчанию (в ОЗУ)
 *   M1 / M0       вкл/выкл поток телеметрии TL … (5 раз/с)
 *
 *  ОБРАБОТКА ОШИБОК: самотест старта; контроль датчика в работе
 *  (тревога при молчании > SENSOR_FAIL_S, автоснятие); медианная
 *  проверка захвата; валидация команд и параметров; защита
 *  буфера; счётчик загрузок в EEPROM (диагностика питания).
 *
 *  ЗАМЕНЫ КОМПОНЕНТОВ — таблицы в руководстве. Ключевое:
 *  JSN-SR04T -> S MINVALID 25; дальнобойные датчики -> таймаут
 *  PULSE_TIMEOUT_US; серво SG90/MG90S/MG996R — без изменений.
 * ============================================================
 */

#include <Servo.h>

#define FW_VERSION "1.2"
#define RADAR_GUI 0        // 1 = поток "угол,дистанция." для Processing-радара
#define USE_EEPROM 1

#if USE_EEPROM
#include <EEPROM.h>
#endif

// ========================= ПИНЫ =============================
const uint8_t PIN_SERVO  = 9;
const uint8_t PIN_TRIG   = 3;
const uint8_t PIN_ECHO   = 2;
const uint8_t PIN_LASER  = 7;
const uint8_t PIN_BUZZER = 8;

// ---- Озвучка DFPlayer Mini (опция, библиотека не нужна) ----
// Дорожки на microSD: /mp3/0001.mp3 старт, 0002 захват,
// 0003 «поражение», 0004 потеря, 0005 тревога датчика.
#ifndef USE_DFPLAYER
#define USE_DFPLAYER 0     // 1 = включить (D11 -> RX плеера через 1 кОм)
#endif
#if USE_DFPLAYER
#include <SoftwareSerial.h>
SoftwareSerial dfSerial(12, 11);   // RX (не используется), TX = D11
const uint8_t DF_VOLUME = 25;      // 0..30
void dfSend(uint8_t cmd, uint16_t param) {
  uint8_t f[10] = {0x7E, 0xFF, 0x06, cmd, 0x00,
                   (uint8_t)(param >> 8), (uint8_t)param, 0, 0, 0xEF};
  int16_t sum = 0;
  for (int i = 1; i < 7; i++) sum += f[i];
  sum = -sum;
  f[7] = (uint8_t)(sum >> 8);
  f[8] = (uint8_t)sum;
  dfSerial.write(f, 10);
}
void dfPlay(uint16_t track) { dfSend(0x03, track); }
void dfSetup() {
  dfSerial.begin(9600);
  delay(600);
  dfSend(0x06, DF_VOLUME);
  delay(80);
  dfPlay(1);
}
#else
void dfPlay(uint16_t) {}
#endif

// ============ ПАРАМЕТРЫ (настраиваются командой S) ==========
int      SWEEP_MIN      = 15;    // S SWMIN
int      SWEEP_MAX      = 165;   // S SWMAX
int      DETECT_DIST_CM = 60;    // S DETECT
int      LOST_DIST_CM   = 90;    // S LOST
int      MIN_VALID_CM   = 3;     // S MINVALID (JSN-SR04T: 25)
int      CONFIRM_PINGS  = 3;     // S CONFIRM
int      LOST_PINGS     = 12;    // S LOSTP
int      TRACK_WOBBLE   = 5;     // S WOBBLE
unsigned int STEP_MS        = 30;    // S STEP
unsigned int KILL_HOLD_MS   = 3000;  // S KILLMS
unsigned int EXT_TIMEOUT_MS = 700;   // S EXTMS
unsigned long TRACK_MAX_MS   = 60000; // S TRACKMAX: лимит непрерывного
                                      // сопровождения, 0 = без лимита
unsigned long TRACK_COOLDOWN_MS = 10000; // S TRACKCD: пауза после лимита

// ================== НЕИЗМЕНЯЕМЫЕ КОНСТАНТЫ ==================
const unsigned long PULSE_TIMEOUT_US = 20000UL; // JSN-SR04T: 30000
const unsigned int  SENSOR_FAIL_S    = 30;

// ======================= СОСТОЯНИЕ ==========================
enum Mode { PATROL, TRACK, SLAVE };
Mode mode = PATROL;

Servo turret;
int  angle = 15, sweepDir = 1;
int  lockAngle = 90, wobble = 0, wobbleDir = 1;
int  confirmCnt = 0, lostCnt = 0;
unsigned long lastStep = 0, lockedAt = 0;
unsigned long cooldownUntil = 0;   // пауза после лимита сопровождения
bool killLogged = false;
unsigned int kills = 0;

int  extAngle = 90;
unsigned long lastExtMs = 0;
char inBuf[20];
uint8_t inLen = 0;

unsigned long lastEchoMs = 0, lastAlarmMs = 0;
bool sensorAlarm = false;

bool telemetryOn = false;
unsigned long lastTlMs = 0;
int lastDist = 999;

#if USE_EEPROM
struct Persist {
  uint16_t magic, boots, kills;
  int16_t detect, lost, minValid, confirm, lostP, wobble, swMin, swMax;
  uint16_t stepMs, killMs, extMs;
  uint32_t trackMax, trackCd;
};
const uint16_t MAGIC = 0x1D09;   // сменён: в структуру добавлены TRACKMAX/TRACKCD
Persist pdata;
#endif

// Прототипы
void patrolStep(); void trackStep(); void slaveStep();
void lockTarget(); void releaseTarget(bool byLimit = false); void logKill();
void pollSerial(); void handleLine(char *s);
int  measureCm(); int measureMedian3();
void report(int a, int d); void victoryTune();
void selfTest(); void sensorWatch(); void noteEcho();
void printParams(); bool setParam(const char *n, long v);
void setDefaults(); void saveAll(); void emitTelemetry();

// ============================================================
void setup() {
  pinMode(PIN_TRIG, OUTPUT);
  pinMode(PIN_ECHO, INPUT);
  pinMode(PIN_LASER, OUTPUT);
  pinMode(PIN_BUZZER, OUTPUT);
  digitalWrite(PIN_LASER, LOW);
  Serial.begin(9600);
  turret.attach(PIN_SERVO);

#if USE_EEPROM
  EEPROM.get(0, pdata);
  if (pdata.magic == MAGIC) {          // параметры из EEPROM
    kills = pdata.kills;
    DETECT_DIST_CM = pdata.detect;  LOST_DIST_CM = pdata.lost;
    MIN_VALID_CM = pdata.minValid;  CONFIRM_PINGS = pdata.confirm;
    LOST_PINGS = pdata.lostP;       TRACK_WOBBLE = pdata.wobble;
    SWEEP_MIN = pdata.swMin;        SWEEP_MAX = pdata.swMax;
    STEP_MS = pdata.stepMs;         KILL_HOLD_MS = pdata.killMs;
    EXT_TIMEOUT_MS = pdata.extMs;
    TRACK_MAX_MS = pdata.trackMax;  TRACK_COOLDOWN_MS = pdata.trackCd;
  } else {
    pdata.magic = MAGIC; pdata.boots = 0; pdata.kills = 0;
  }
  pdata.boots++;
  saveAll();
#endif
  angle = SWEEP_MIN;

  selfTest();
#if USE_DFPLAYER
  dfSetup();
#endif

#if !RADAR_GUI
  Serial.println(F("=== ПВО-1К \"Комар\" (полная прошивка) на боевом дежурстве ==="));
  Serial.println(F("Версия прошивки: " FW_VERSION));
#if USE_EEPROM
  Serial.print(F("Загрузка N")); Serial.print(pdata.boots);
  Serial.print(F(", журнал за всё время: ")); Serial.println(kills);
  if (pdata.boots > 3)
    Serial.println(F("Подсказка: если счётчик загрузок растёт сам — проверьте питание серво"));
#endif
  Serial.println(F("Команды: P<угол> R ? G S W D Z M1/M0 (подробнее — руководство)"));
#endif
  lastEchoMs = millis();
}

// ============================================================
void loop() {
  pollSerial();

  unsigned long now = millis();
  if (now - lastStep < STEP_MS) return;
  lastStep = now;

  if (mode != SLAVE) sensorWatch();

  if (mode != PATROL && TRACK_MAX_MS > 0 && now - lockedAt > TRACK_MAX_MS) {
    cooldownUntil = now + TRACK_COOLDOWN_MS;   // пауза перед новым захватом
    releaseTarget(true);
  }

  if      (mode == PATROL) patrolStep();
  else if (mode == TRACK)  trackStep();
  else                     slaveStep();

  emitTelemetry();
}

// ---------------- САМОТЕСТ ----------------------------------
void selfTest() {
  turret.write(90); delay(400);
  turret.write(SWEEP_MIN); delay(400);
  turret.write(SWEEP_MAX); delay(600);
  turret.write(90); delay(400);
  for (int i = 0; i < 2; i++) {
    digitalWrite(PIN_LASER, HIGH); delay(120);
    digitalWrite(PIN_LASER, LOW);  delay(120);
  }
  int ok = 0;
  for (int i = 0; i < 10; i++) { if (measureCm() < 999) ok++; delay(40); }
#if !RADAR_GUI
  if (ok == 0) {
    Serial.println(F("ОШИБКА САМОТЕСТА: датчик не дал ни одного эха (TRIG->D3, ECHO->D2, 5V, GND?)"));
    Serial.println(F("  Для связки с Raspberry Pi (SLAVE) турель всё равно работоспособна."));
    tone(PIN_BUZZER, 300, 400);
  } else {
    Serial.print(F("Самотест: датчик OK (эхо в ")); Serial.print(ok); Serial.println(F("/10 замеров)"));
  }
#endif
  tone(PIN_BUZZER, 880, 90); delay(120);
  tone(PIN_BUZZER, 1320, 90); delay(150);
}

// ---------------- ЗДОРОВЬЕ ДАТЧИКА --------------------------
void sensorWatch() {
  unsigned long now = millis();
  if (now - lastEchoMs > (unsigned long)SENSOR_FAIL_S * 1000UL) {
    if (!sensorAlarm || now - lastAlarmMs > 60000UL) {
      sensorAlarm = true;
      lastAlarmMs = now;
#if !RADAR_GUI
      Serial.println(F("ТРЕВОГА: датчик молчит (нет ни одного эха). Обрыв TRIG/ECHO/питания?"));
#endif
      dfPlay(5);
      tone(PIN_BUZZER, 300, 100); delay(140); tone(PIN_BUZZER, 300, 100);
    }
  }
}

void noteEcho() {
  lastEchoMs = millis();
  if (sensorAlarm) {
    sensorAlarm = false;
#if !RADAR_GUI
    Serial.println(F("Датчик снова отвечает — тревога снята"));
#endif
  }
}

// ---------------- ПРИЁМ КОМАНД ------------------------------
void pollSerial() {
  while (Serial.available()) {
    char c = (char)Serial.read();
    if (c == '\n' || c == '\r') {
      if (inLen > 0) { inBuf[inLen] = '\0'; handleLine(inBuf); inLen = 0; }
    } else if (inLen < sizeof(inBuf) - 1) {
      inBuf[inLen++] = c;
    } else {
      inLen = 0;
    }
  }
}

void handleLine(char *s) {
  if (s[0] == 'P' && s[1] >= '0' && s[1] <= '9') {
    int a = atoi(s + 1);
    if (a < SWEEP_MIN) a = SWEEP_MIN;
    if (a > SWEEP_MAX) a = SWEEP_MAX;
    extAngle  = a;
    lastExtMs = millis();
    if (mode != SLAVE && millis() >= cooldownUntil) {
      mode = SLAVE;
      killLogged = false;
      lockedAt = millis();
      digitalWrite(PIN_LASER, HIGH);
      tone(PIN_BUZZER, 1200, 80);
#if !RADAR_GUI
      Serial.println(F(">>> Внешнее целеуказание принято (SLAVE)"));
#endif
    }
  } else if (s[0] == 'R' && s[1] == '\0') {
    if (mode == SLAVE) releaseTarget();
  } else if (s[0] == '?' ) {
#if !RADAR_GUI
    Serial.print(F("СТАТУС: режим="));
    Serial.print(mode == PATROL ? F("ПАТРУЛЬ")
                : mode == TRACK ? F("СОПРОВОЖДЕНИЕ") : F("SLAVE"));
    Serial.print(F(", журнал=")); Serial.print(kills);
    Serial.print(F(", датчик=")); Serial.print(sensorAlarm ? F("МОЛЧИТ") : F("OK"));
    if (millis() < cooldownUntil) {
      Serial.print(F(", ПАУЗА ещё "));
      Serial.print((cooldownUntil - millis()) / 1000); Serial.print(F(" c"));
    }
#if USE_EEPROM
    Serial.print(F(", загрузок=")); Serial.print(pdata.boots);
#endif
    Serial.println(F(", прошивка=" FW_VERSION));
#endif
  } else if (s[0] == 'G' && s[1] == '\0') {
    printParams();
  } else if (s[0] == 'S' && s[1] == ' ') {
    char *name = s + 2;
    char *sp = strchr(name, ' ');
    if (sp == NULL) {
      Serial.println(F("ERR формат: S ИМЯ ЗНАЧЕНИЕ"));
      return;
    }
    *sp = '\0';
    long v = atol(sp + 1);
    if (setParam(name, v)) {
      Serial.print(F("OK ")); Serial.print(name);
      Serial.print(F("=")); Serial.println(v);
    } else {
      Serial.print(F("ERR имя или диапазон: ")); Serial.println(name);
    }
  } else if (s[0] == 'W' && s[1] == '\0') {
#if USE_EEPROM
    saveAll();
    Serial.println(F("OK SAVED (параметры и журнал в EEPROM)"));
#else
    Serial.println(F("ERR EEPROM отключён (USE_EEPROM 0)"));
#endif
  } else if (s[0] == 'D' && s[1] == '\0') {
    setDefaults();
    Serial.println(F("OK DEFAULTS (в ОЗУ; W — сохранить)"));
  } else if (s[0] == 'Z' && s[1] == '\0') {
    kills = 0;
#if USE_EEPROM
    saveAll();
#endif
    Serial.println(F("OK Z (журнал поражений обнулён)"));
  } else if (s[0] == 'M' && (s[1] == '0' || s[1] == '1')) {
    telemetryOn = (s[1] == '1');
    Serial.println(telemetryOn ? F("OK M1") : F("OK M0"));
  } else {
#if !RADAR_GUI
    Serial.println(F("ОШИБКА КОМАНДЫ: известны P<угол> R ? G S W D Z M1/M0"));
#endif
  }
}

// ---------------- ПАРАМЕТРЫ: G / S / W / D ------------------
void printParams() {
  Serial.print(F("PARAM DETECT="));   Serial.println(DETECT_DIST_CM);
  Serial.print(F("PARAM LOST="));     Serial.println(LOST_DIST_CM);
  Serial.print(F("PARAM MINVALID=")); Serial.println(MIN_VALID_CM);
  Serial.print(F("PARAM CONFIRM=")); Serial.println(CONFIRM_PINGS);
  Serial.print(F("PARAM LOSTP="));    Serial.println(LOST_PINGS);
  Serial.print(F("PARAM WOBBLE="));   Serial.println(TRACK_WOBBLE);
  Serial.print(F("PARAM STEP="));     Serial.println(STEP_MS);
  Serial.print(F("PARAM KILLMS="));   Serial.println(KILL_HOLD_MS);
  Serial.print(F("PARAM EXTMS="));    Serial.println(EXT_TIMEOUT_MS);
  Serial.print(F("PARAM TRACKMAX=")); Serial.println(TRACK_MAX_MS);
  Serial.print(F("PARAM TRACKCD="));  Serial.println(TRACK_COOLDOWN_MS);
  Serial.print(F("PARAM SWMIN="));    Serial.println(SWEEP_MIN);
  Serial.print(F("PARAM SWMAX="));    Serial.println(SWEEP_MAX);
  Serial.println(F("PARAM END"));
}

bool inRange(long v, long lo, long hi) { return v >= lo && v <= hi; }

bool setParam(const char *n, long v) {
  if      (!strcmp(n, "DETECT")   && inRange(v, 5, 300))  DETECT_DIST_CM = v;
  else if (!strcmp(n, "LOST")     && inRange(v, 5, 400))  LOST_DIST_CM = v;
  else if (!strcmp(n, "MINVALID") && inRange(v, 1, 50))   MIN_VALID_CM = v;
  else if (!strcmp(n, "CONFIRM")  && inRange(v, 1, 10))   CONFIRM_PINGS = v;
  else if (!strcmp(n, "LOSTP")    && inRange(v, 1, 50))   LOST_PINGS = v;
  else if (!strcmp(n, "WOBBLE")   && inRange(v, 1, 20))   TRACK_WOBBLE = v;
  else if (!strcmp(n, "STEP")     && inRange(v, 20, 100)) STEP_MS = v;
  else if (!strcmp(n, "KILLMS")   && inRange(v, 200, 20000)) KILL_HOLD_MS = v;
  else if (!strcmp(n, "EXTMS")    && inRange(v, 200, 5000))  EXT_TIMEOUT_MS = v;
  else if (!strcmp(n, "TRACKMAX") && (v == 0 || inRange(v, 5000, 600000))) TRACK_MAX_MS = v;
  else if (!strcmp(n, "TRACKCD")  && inRange(v, 0, 120000))  TRACK_COOLDOWN_MS = v;
  else if (!strcmp(n, "SWMIN")    && inRange(v, 0, 170) && v < SWEEP_MAX) SWEEP_MIN = v;
  else if (!strcmp(n, "SWMAX")    && inRange(v, 10, 180) && v > SWEEP_MIN) SWEEP_MAX = v;
  else return false;
  return true;
}

void setDefaults() {
  DETECT_DIST_CM = 60; LOST_DIST_CM = 90; MIN_VALID_CM = 3;
  CONFIRM_PINGS = 3; LOST_PINGS = 12; TRACK_WOBBLE = 5;
  STEP_MS = 30; KILL_HOLD_MS = 3000; EXT_TIMEOUT_MS = 700;
  SWEEP_MIN = 15; SWEEP_MAX = 165;
  TRACK_MAX_MS = 60000; TRACK_COOLDOWN_MS = 10000;
}

void saveAll() {
#if USE_EEPROM
  pdata.kills = kills;
  pdata.detect = DETECT_DIST_CM;  pdata.lost = LOST_DIST_CM;
  pdata.minValid = MIN_VALID_CM;  pdata.confirm = CONFIRM_PINGS;
  pdata.lostP = LOST_PINGS;       pdata.wobble = TRACK_WOBBLE;
  pdata.swMin = SWEEP_MIN;        pdata.swMax = SWEEP_MAX;
  pdata.stepMs = STEP_MS;         pdata.killMs = KILL_HOLD_MS;
  pdata.extMs = EXT_TIMEOUT_MS;
  pdata.trackMax = TRACK_MAX_MS;  pdata.trackCd = TRACK_COOLDOWN_MS;
  EEPROM.put(0, pdata);
#endif
}

// ---------------- ТЕЛЕМЕТРИЯ ДЛЯ GUI ------------------------
void emitTelemetry() {
  if (!telemetryOn) return;
  unsigned long now = millis();
  if (now - lastTlMs < 200) return;
  lastTlMs = now;
  int a = (mode == PATROL) ? angle : (mode == TRACK ? lockAngle + wobble : extAngle);
  Serial.print(F("TL m="));
  Serial.print(mode == PATROL ? 'P' : (mode == TRACK ? 'T' : 'S'));
  Serial.print(F(" a=")); Serial.print(a);
  Serial.print(F(" d=")); Serial.print(lastDist);
  Serial.print(F(" k=")); Serial.print(kills);
  Serial.print(F(" s=")); Serial.println(sensorAlarm ? 1 : 0);
}

// ---------------- SLAVE -------------------------------------
void slaveStep() {
  if (millis() - lastExtMs > EXT_TIMEOUT_MS) {
#if !RADAR_GUI
    Serial.println(F("Командир молчит — перехожу в автономию"));
#endif
    releaseTarget();
    return;
  }
  turret.write(extAngle);
  int d = measureCm();
  report(extAngle, d);
  if (!killLogged && millis() - lockedAt >= KILL_HOLD_MS) logKill();
}

// ---------------- ПАТРУЛЬ -----------------------------------
void patrolStep() {
  angle += sweepDir;
  if (angle >= SWEEP_MAX) { angle = SWEEP_MAX; sweepDir = -1; }
  if (angle <= SWEEP_MIN) { angle = SWEEP_MIN; sweepDir =  1; }
  turret.write(angle);

  int d = measureCm();
  report(angle, d);

  if (millis() < cooldownUntil) {
    confirmCnt = 0;                       // пауза после лимита сопровождения
  } else if (d >= MIN_VALID_CM && d <= DETECT_DIST_CM) {
    if (++confirmCnt >= CONFIRM_PINGS) {
      int m = measureMedian3();
      if (m >= MIN_VALID_CM && m <= DETECT_DIST_CM) lockTarget();
      else confirmCnt = 0;
    }
  } else {
    confirmCnt = 0;
  }
}

// ---------------- ЗАХВАТ / СОПРОВОЖДЕНИЕ --------------------
void lockTarget() {
  mode = TRACK;
  lockAngle = angle;
  wobble = 0; wobbleDir = 1;
  lostCnt = 0; killLogged = false;
  lockedAt = millis();
  digitalWrite(PIN_LASER, HIGH);
  dfPlay(2);
  tone(PIN_BUZZER, 1200, 80);
#if !RADAR_GUI
  Serial.print(F(">>> ЦЕЛЬ ЗАХВАЧЕНА! Азимут "));
  Serial.print(lockAngle); Serial.println(F(" град — лазер наведён"));
#endif
}

void trackStep() {
  wobble += wobbleDir;
  if (wobble >=  TRACK_WOBBLE) wobbleDir = -1;
  if (wobble <= -TRACK_WOBBLE) wobbleDir =  1;
  int a = constrain(lockAngle + wobble, SWEEP_MIN, SWEEP_MAX);
  turret.write(a);

  int d = measureCm();
  report(a, d);

  if (d >= MIN_VALID_CM && d <= LOST_DIST_CM) {
    lostCnt = 0;
    lockAngle = a;
    if (!killLogged && millis() - lockedAt >= KILL_HOLD_MS) logKill();
  } else if (++lostCnt >= LOST_PINGS) {
    releaseTarget();
  }
}

void logKill() {
  kills++;
  killLogged = true;
#if USE_EEPROM
  saveAll();
#endif
  dfPlay(3);
  victoryTune();
#if !RADAR_GUI
  Serial.print(F("*** Цель N")); Serial.print(kills);
  Serial.println(F(" поражена. Занесена в журнал ***"));
#endif
}

void releaseTarget(bool byLimit) {
  digitalWrite(PIN_LASER, LOW);
  angle = (mode == SLAVE) ? extAngle : lockAngle;
  if (angle < SWEEP_MIN) angle = SWEEP_MIN;
  if (angle > SWEEP_MAX) angle = SWEEP_MAX;
  mode = PATROL;
  confirmCnt = 0;
  dfPlay(4);
  tone(PIN_BUZZER, 400, 120);
#if !RADAR_GUI
  if (byLimit)
    Serial.println(F("<<< Лимит непрерывного сопровождения — пауза, лазер погашен"));
  else
    Serial.println(F("<<< Цель потеряна — возвращаюсь к патрулированию"));
#endif
}

// ---------------- ЗАМЕРЫ ------------------------------------
int measureCm() {
  digitalWrite(PIN_TRIG, LOW);  delayMicroseconds(2);
  digitalWrite(PIN_TRIG, HIGH); delayMicroseconds(10);
  digitalWrite(PIN_TRIG, LOW);
  unsigned long us = pulseIn(PIN_ECHO, HIGH, PULSE_TIMEOUT_US);
  if (us == 0) { lastDist = 999; return 999; }
  noteEcho();
  int cm = (int)(us / 58);
  if (cm < 1) cm = 999;
  lastDist = cm;
  return cm;
}

int measureMedian3() {
  int a = measureCm(); delay(30);
  int b = measureCm(); delay(30);
  int c = measureCm();
  if (a > b) { int t = a; a = b; b = t; }
  if (b > c) { int t = b; b = c; c = t; }
  if (a > b) { int t = a; a = b; b = t; }
  return b;
}

// ---------------- ТЕЛЕМЕТРИЯ / ЗВУК -------------------------
void report(int a, int d) {
#if RADAR_GUI
  Serial.print(a); Serial.print(','); Serial.print(d); Serial.print('.');
#else
  (void)a; (void)d;
#endif
}

void victoryTune() {
  tone(PIN_BUZZER, 1568, 100); delay(120);
  tone(PIN_BUZZER, 1245, 100); delay(120);
  tone(PIN_BUZZER, 1047, 180);
}

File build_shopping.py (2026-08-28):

# -*- coding: utf-8 -*-
"""Чеклист закупки комплектующих для проекта «ПВО от комаров»."""
from openpyxl import Workbook
from openpyxl.styles import Font, PatternFill, Alignment, Border, Side
from openpyxl.utils import get_column_letter

TEAL = "00575C"
LIGHT = "E8F1F2"
SEC = "D3E3E5"
YELLOW = "FFF2CC"
thin = Side(style="thin", color="B7C9CB")
border = Border(left=thin, right=thin, top=thin, bottom=thin)

wb = Workbook()
ws = wb.active
ws.title = "Список покупок"

widths = {"A": 4.5, "B": 42, "C": 7, "D": 46, "E": 13, "F": 12, "G": 10, "H": 46}
for c, w in widths.items():
    ws.column_dimensions[c].width = w

def cell(r, c, v, *, bold=False, size=10, color="000000", fill=None, wrap=True,
         center=False, fmt=None, italic=False):
    cl = ws.cell(row=r, column=c, value=v)
    cl.font = Font(name="Arial", size=size, bold=bold, color=color, italic=italic)
    cl.alignment = Alignment(vertical="center", wrap_text=wrap,
                             horizontal="center" if center else "left")
    if fill:
        cl.fill = PatternFill("solid", fgColor=fill)
    if fmt:
        cl.number_format = fmt
    cl.border = border
    return cl

r = 1
ws.merge_cells(f"A{r}:H{r}")
cell(r, 1, "ПВО ОТ КОМАРОВ — полный список комплектующих (рекомендация)", bold=True, size=14, color="FFFFFF", fill=TEAL, center=True)
ws.row_dimensions[r].height = 24
r += 1
ws.merge_cells(f"A{r}:H{r}")
cell(r, 1, "Цены ориентировочные (Ozon/WB/AliExpress, авг 2026) — правьте синие ячейки под свои; жёлтая колонка «Куплено» — для отметок (любой символ). Итоги пересчитаются сами.",
     italic=True, size=9, color="555555")
ws.row_dimensions[r].height = 26
r += 2

HEAD = ["№", "Компонент", "Кол-во", "Зачем нужен", "Цена/шт, ₽", "Сумма, ₽", "Куплено", "Примечание"]

sections = [
    ("1. БАЗОВЫЙ НАБОР — нужен при любом варианте", [
        ("Лазерный модуль KY-008 (красный, ≤5 мВт)", 1, 100, "целеуказатель турели",
         "СТРОГО не мощнее 5 мВт — безопасность зрения"),
        ("Буззер активный 5 В", 1, 50, "звуки захвата и «поражения»", "пьезо тоже подойдёт"),
        ("Провода Dupont, набор 3×40 шт (п-п, п-м, м-м)", 1, 250, "вся коммутация без пайки", "20 см удобнее всего"),
        ("Макетная плата 830 точек", 1, 250, "сборка схемы без пайки", "или 400 точек за ~150 ₽"),
        ("Блок питания 5 В / 3 А (штекер 5,5×2,1)", 1, 450, "питание серво и радара", "3 А закрывает варианты A и B с запасом"),
        ("Переходник DC 5,5×2,1 → клеммник", 1, 60, "подключить БП к макетке", ""),
        ("Конденсатор 1000 мкФ / 16 В", 2, 20, "сглаживание бросков тока серво", "ставится по питанию серво"),
        ("Основание (фанера/пластик) + винты М2/М3, набор", 1, 200, "неподвижная база турели", "подойдёт и обрезок доски"),
    ]),
    ("2. ЯДРО «КАК В ВИДЕО» — вариант B (рекомендую)", [
        ("ESP32 DevKit V1 (WROOM-32, 30 pin)", 1, 550, "мозг: приём радара, наведение, Wi-Fi на будущее",
         "берите с распаянными гребёнками; чип USB — CP2102 или CH340"),
        ("Радар HLK-LD2450", 1, 800, "координаты до 3 движущихся целей, 256000 бод",
         "альтернатива: Ai-Thinker RD-03D ~550 ₽ (протокол совместим, поддержан прошивкой)"),
        ("Серво MG90S (металлический редуктор)", 2, 230, "оси pan и tilt", "SG90 дешевле, но люфтит и живёт меньше"),
        ("Pan-tilt кронштейн под SG90/MG90S", 1, 300, "механика двух осей", "готовый комплект с винтами"),
        ("Транзистор 2N2222 (или BC337)", 2, 10, "ключ лазера от GPIO 3,3 В", "второй — про запас"),
        ("Резисторы 1 кОм (набор)", 1, 60, "в базу транзистора", "любой набор выводных резисторов"),
        ("Кабель USB для прошивки (с линиями данных!)", 1, 150, "прошивка и монитор порта",
         "смотрите разъём своей платы: micro-USB или USB-C; «зарядные» кабели не годятся"),
    ]),
    ("3. БЮДЖЕТНЫЙ СТАРТ — вариант A (если начать проще)", [
        ("Arduino Nano (CH340, распаянный)", 1, 400, "мозг сканирующей турели", "или Uno R3 клон ~600 ₽; понадобится драйвер CH340"),
        ("Ультразвуковой дальномер HC-SR04", 1, 100, "«радар»: дистанция до цели", ""),
        ("Серво SG90", 1, 160, "ось азимута", "можно взять MG90S из раздела 2 — он лучше"),
        ("Кабель mini-USB (Nano) или USB-B (Uno)", 1, 130, "прошивка", "тоже с линиями данных"),
    ]),
    ("4. АПГРЕЙД «ЗРЕНИЕ» — вариант C (можно докупить потом)", [
        ("Raspberry Pi 4 (4 ГБ)", 1, 6500, "компьютерное зрение (OpenCV)", "или Pi 5; бюджетно — Zero 2 W ~3000 ₽ (ниже FPS)"),
        ("Камера USB 1080p (или Camera Module 3)", 1, 900, "«глаза» системы", "CSI-модуль ~4000 ₽ — лучше в темноте, нужен шлейф под вашу Pi"),
        ("microSD 32 ГБ (класс A1/U3)", 1, 500, "система Raspberry Pi OS", "качественная карта — залог стабильности"),
        ("БП USB-C 5 В / 3 А", 1, 900, "питание Raspberry Pi", "фирменный или качественный — Pi чувствительна к просадкам"),
        ("Корпус с охлаждением / радиаторы", 1, 500, "тепловой режим Pi", "необязательно, но желательно"),
    ]),
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

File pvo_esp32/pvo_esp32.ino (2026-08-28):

/*
 * ============================================================
 *  ПВО-2К «Комар-М» — ВАРИАНТ B: ESP32 + mmWave-радар
 * ============================================================
 *  ESP32 DevKit + LD2450/RD-03D + 2 серво (pan-tilt) + лазер
 *  <=5 мВт через транзистор + буззер. Ядро Arduino-ESP32 3.x,
 *  библиотека ESP32Servo. Схема и сборка — «Сборка варианта B».
 *
 *  ЛОГИКА: ДЕЖУРСТВО (ленивый патруль) ⇄ СОПРОВОЖДЕНИЕ.
 *
 *  ПРОТОКОЛ (Монитор порта / GUI pvo_gui.py, 115200, строки \n):
 *   ?             статус
 *   C             серво в центр на 8 с (юстировка)
 *   L1 / L0       тест лазера (только на дежурстве)
 *   T             повторная инициализация радара
 *   G             все параметры: PARAM ИМЯ=ЗНАЧ … PARAM END
 *   S ИМЯ ЗНАЧ    установить параметр (дроби ×100: S ALPHA 35)
 *   W             сохранить параметры и журнал в NVS
 *   D             параметры по умолчанию (в ОЗУ)
 *   M1 / M0       поток телеметрии TL … (5 раз/с)
 *   V dP dT       точная поправка от зрения, в десятых градуса
 *                 (вариант D: камера на турели; при дежурстве —
 *                 захват зрением, радар не обязателен)
 *   I1 / I0       ИК-подсветка вручную (GPIO18 через ключ)
 *
 *  ОБРАБОТКА ОШИБОК: самотест; контроль связи с радаром
 *  (тревога, автопереинициализация RD-03D, автоснятие);
 *  счётчики битых кадров с подсказкой; проверка attach() серво;
 *  валидация целей и параметров; журнал в NVS.
 *
 *  ЗАМЕНЫ КОМПОНЕНТОВ — таблицы в руководстве. Ключевое:
 *  LD2450 <-> RD-03D: RADAR_TYPE ниже; серво SG90/MG90S/MG996R —
 *  без изменений (MG996R — БП 5В/2А); транзистор 2N2222/BC337/
 *  S8050 — без изменений, BC547 — другая цоколёвка, MOSFET
 *  2N7000 — без резистора базы; LD2410 НЕ подходит (нет координат).
 * ============================================================
 */

#include <ESP32Servo.h>
#include <math.h>

#define FW_VERSION "1.3"
#define RADAR_TYPE 1   // 0 = HLK-LD2450, 1 = Ai-Thinker RD-03D
#define USE_NVS 1

// ---- Wi-Fi веб-панель (радар и настройки в браузере телефона) ----
#ifndef WIFI_ENABLED
#define WIFI_ENABLED 1     // 0 = полностью выключить веб
#endif
#define WIFI_AP_MODE 1     // 1 = турель раздаёт свою сеть, 0 = подключается к домашней
const char *WIFI_SSID = "PVO-Komar";    // AP: имя своей сети / STA: имя домашней сети
const char *WIFI_PASS = "komar12345";   // минимум 8 символов
const char *WEB_USER = "";              // логин веб-панели ("" = без пароля)
const char *WEB_PASS = "";              // пароль веб-панели

// ---- OLED-экран SSD1306 128x64 по I2C (опция, нужна библиотека) ----
#ifndef USE_OLED
#define USE_OLED 0         // 1 = включить (Менеджер библиотек: Adafruit SSD1306 + GFX)
#endif

// ---- Озвучка DFPlayer Mini (опция, библиотека не нужна) ----
#ifndef USE_DFPLAYER
#define USE_DFPLAYER 0     // 1 = включить (TX ESP32 GPIO33 -> RX DFPlayer через 1 кОм)
#endif

#if USE_NVS
#include <Preferences.h>
Preferences prefs;
#endif

#if WIFI_ENABLED
#include <WiFi.h>
#include <WebServer.h>
WebServer web(80);
#endif

#if USE_OLED
#include <Wire.h>
#include <Adafruit_GFX.h>
#include <Adafruit_SSD1306.h>
Adafruit_SSD1306 oled(128, 64, &Wire, -1);
bool oledOk = false;
uint32_t lastOledMs = 0;
#endif

// ========================= ПИНЫ =============================
const int PIN_RADAR_RX = 16;
const int PIN_RADAR_TX = 17;
const int PIN_SERVO_PAN  = 26;
const int PIN_SERVO_TILT = 27;
const int PIN_LASER  = 23;
const int PIN_BUZZER = 19;
const int PIN_IR     = 18;   // ИК-подсветка через ключ (вариант D)

// ============ ПАРАМЕТРЫ (настраиваются командой S) ==========
int   PAN_CENTER  = 90;    // S PANC
int   PAN_MIN     = 15;    // S PANMIN
int   PAN_MAX     = 165;   // S PANMAX
int   TILT_CENTER = 90;    // S TILTC
int   TILT_MIN    = 60;    // S TILTMIN
int   TILT_MAX    = 120;   // S TILTMAX
bool  PAN_INVERT  = false; // S PANINV 0/1
bool  TILT_INVERT = false; // S TILTINV 0/1
bool  AUTO_TILT   = true;  // S ATILT 0/1
int   TURRET_HEIGHT_MM = 750;   // S TURH
int   TARGET_HEIGHT_MM = 1100;  // S TGTH
int   MIN_RANGE_MM = 300;   // S MINR
int   MAX_RANGE_MM = 4000;  // S MAXR
float MAX_AZ_DEG   = 60.0f; // S MAXAZ (в градусах)
int   LOCK_CONFIRM_FRAMES = 5;    // S CONFIRM
uint32_t LOST_TIMEOUT_MS  = 700;  // S LOSTMS
uint32_t KILL_HOLD_MS     = 3000; // S KILLMS
float SMOOTH_ALPHA = 0.35f; // S ALPHA (×100: 35)
float SLEW_DEG_MAX = 6.0f;  // S SLEW
bool  PATROL_ENABLED = true;   // S PATROL 0/1
float PATROL_SPEED   = 0.35f;  // S PSPEED (×100: 35)
bool  IR_AUTO        = true;   // S IRAUTO 0/1: ИК сам при захвате
uint32_t VISION_TIMEOUT_MS = 700; // S VISTO: тишина зрения -> радар
uint32_t TRACK_MAX_MS = 60000;    // S TRACKMAX: лимит непрерывного
                                  // сопровождения (0 = без лимита)
uint32_t TRACK_COOLDOWN_MS = 10000; // S TRACKCD: пауза после лимита

// ================== НЕИЗМЕНЯЕМОЕ ============================
const uint32_t SERVO_PERIOD_MS = 20;
#define TARGET_SELECT 0   // 0 = ближайшая, 1 = самая быстрая
const uint32_t RADAR_SILENT_MS = 2000;
const uint32_t RADAR_RETRY_MS  = 3000;
const uint32_t RADAR_HINT_MS   = 15000;
const float    BAD_FRAME_RATIO = 0.2f;

// ============================================================
struct RadarTarget { bool valid; int16_t x_mm, y_mm, speed_cms; uint16_t res_mm; };

enum Mode { IDLE, TRACK };
Mode mode = IDLE;

Servo servoPan, servoTilt;
RadarTarget targets[3];
uint8_t frameBuf[30];
int frameFill = 0;

float panNow = 90, panGoal = 90, tiltNow = 90, tiltGoal = 90;
float patrolDir = 1.0f;

int confirmCnt = 0;
uint32_t lastSeenMs = 0, lockedAtMs = 0, lastServoMs = 0;
bool killLogged = false;
unsigned kills = 0;
uint16_t boots = 0;

uint32_t lastFrameMs = 0, lastRetryMs = 0, lastHintMs = 0;
bool radarAlarm = false;
uint32_t framesOk = 0, framesBad = 0, framesOkAtStat = 0, statMs = 0;

char conBuf[24];
uint8_t conLen = 0;
uint32_t holdUntil = 0;
bool laserTest = false;

bool telemetryOn = false;
uint32_t lastTlMs = 0;
int tlX = 0, tlY = 0, tlD = 0;   // последняя цель для телеметрии

// --- слияние с зрением (вариант D) ---
bool visionActive = false;       // свежие поправки V от камеры
uint32_t lastVisionMs = 0;
bool irOn = false;

// --- защита от «вечного» сопровождения (штора, вентилятор, экран) ---
uint32_t cooldownUntilMs = 0;    // до этого времени новые захваты запрещены

const uint8_t MULTI_CMD[12] =
  {0xFD, 0xFC, 0xFB, 0xFA, 0x02, 0x00, 0x90, 0x00, 0x04, 0x03, 0x02, 0x01};

void dfPlay(uint16_t track);   // озвучка (пустышка, если USE_DFPLAYER 0)

// ------------------------------------------------------------
int16_t radarInt16(uint8_t lo, uint8_t hi) {
  int16_t mag = (int16_t)((((uint16_t)hi << 8) | lo) & 0x7FFF);
  return (hi & 0x80) ? mag : (int16_t)-mag;
}
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
